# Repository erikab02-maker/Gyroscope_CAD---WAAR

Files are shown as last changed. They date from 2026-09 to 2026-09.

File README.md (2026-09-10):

I designed a gyroscope with Skye Kaser for the Washington Aerial Robotics Club (WAAR) at the University of Washington during the 2025-2026 academic year. Designing the gyroscope involved multiple design iterations, where I learned from each design to improve the following iteration in such a way as to reduce materials, improve safety factors and stability, and meet design requirements. This entire process allowed me to go through the design cycle from brainstorming ideas, to parameterizing the object in SolidWorks, 3D printing components, assembling components in real life, testing the gyroscope and re-designing. I went through two iterations of the design, with the first iteration having some problems with tolerances, the functionality of the rotation of the base, and the use of excess materials. After finding the areas of improvement I collaborated with Skye on how we could re-design or alter pre-existing CAD to engineer a second iteration of the gyroscope. The final product had significant improvement with the connection to the ball bearings in the top octagon by re-designing the connector, the base rotated much more easily, the base stand was designed to have more support and prevent bending while being transported and overall, less material was used which prevented warping when printing the components. Through the process of working with another engineer to design the gyroscope, I learned collaboration and teamwork skills by communicating design ideas and concerns for the functionality of certain components. I also gained experience utilizing SolidWorks to create the individual components, and in engineering design by going through the entire cycle of designing, evaluating and re-designing.

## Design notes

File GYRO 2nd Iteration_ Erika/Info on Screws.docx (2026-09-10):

Information on Screws

- 0.15 – 0.2 mm tolerance
- 2.5 mm diameter screws
- 8 mm length
- Have at least 6 mm depth to go into

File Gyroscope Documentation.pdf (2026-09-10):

# Gyroscope Test Bed

## Base Information

Test Name: Gyroscope Test Bed

Subsystem: Hardware

Authors: Erika Berreth and Skye Kaser

Date Executed: April 10th, 2026 - | July 6th, 2026
For Discovery Days: April 28th, 2026 - | May 1st, 2026

Location: University of Washington

Status: Completed

## Objective

The objective of this design is to create a gyroscope that has the degrees of freedom to rotate about the x, y, and x axis so that roll, pitch, and yaw capabilities are simulated about the drone. The gyroscope’s purpose is to allow the software team to fine tune the PID controller by simulating disturbances in all degrees of freedom with the gyroscope.

## Related Documents

Link to Bearing Orders: Current Order | McMaster-Carr (https://www.mcmaster.com/orders/)

Design Model Website: 3D Flight Lab – 3DFlightlab (https://3dflightlab.com/)

Gyroscope CAD Folder: WAAR_Gyro_Iteration01and02_2026_ErikaAndSkye (https://drive.google.com/drive/folders/1tEqzYJV6UX54x_FTIXxHvfCaPLfKlcOg?usp=drive_link)

## Equipment

Ball Bearing, 0.25’’ diameter (x 4)

Needle-Roller Thrust Bearing with 2.5’’ diameter (x 1)

0.032" Thick Washer for 2.5" Shaft Diameter Needle-Roller Thrust Bearing (x 2 )

Gyroscope Test Bed | 1

PLA for 3D printing

PVC pipe with 0.5 inch diameter

Add screws

## Requirements and Constraints

Requirement | Value | Notes | Status
Degrees of Freedom | = 3 DOF | Must have pitch, roll and yaw capabilities. | MET
Safety Requirements | The design must create a cage around the drone, and the drone must be rigidly mounted. | Prevent user injury and damage during operation. | MET
Load Capabilities | The gyroscope should be able to withstand vibrations from the drone and rotational forces. | Ensures structural integrity under forces and vibrations from the drone. | MET
Cost | The gyroscope should be less than $60. | Try to keep bearings under $5 each. | MET

## Design Idea

The gyroscope will look similar to the design as seen below in Figure 1, with an octagonal top structure that has two degrees of freedom and four ball bearings, and a base that has one degree of freedom and two thrust bearings. The drone will be attached to the drone support frame with ideally four velcro straps or zip ties.

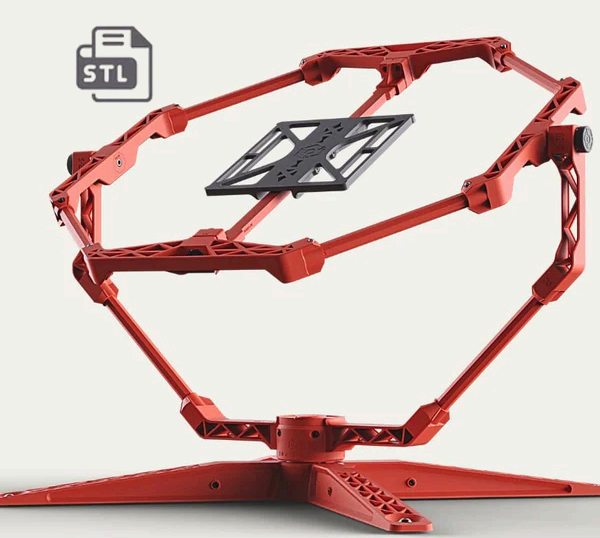
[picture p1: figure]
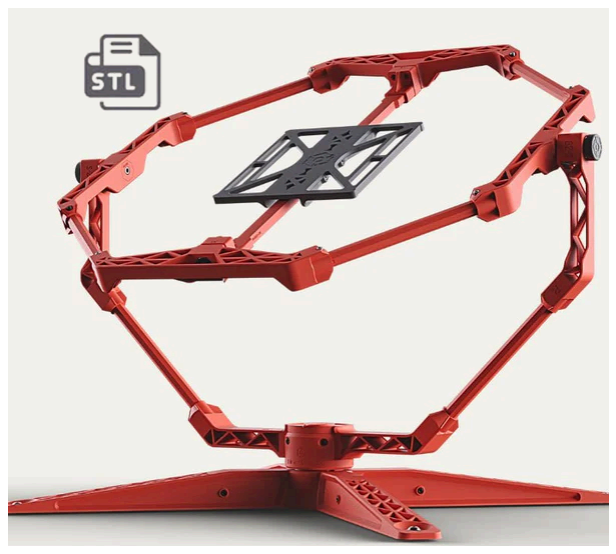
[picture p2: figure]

## Design Procedure

Overview

Figure 1: Image of the inspiration behind the model for the gyroscope.

Following the design of the previously shown image to create a fully 3D printed gyroscope utilizing the cheapest and quickest methods. Time is of the essence and cost is a factor. Bearings were selected to fit a tight cost criteria and the design will revolve around them. If the budget allows, larger thrust bearings can be purchased to better support the weight of the drone and prevent wobbling. The base stand, base, base connectors, vertical connectors, and four components of the octagon were designed in SolidWorks. The thin circular rods that connect each of the components was not 3D printed but made of PVC. No bearing caps were needed like in the image, as the ball bearings were designed to fit in a small cut extrude feature. The base stand was made to be a shelled component, that was filled with sand for weight.

Vertical Connector to Octagon

The gyroscope was designed to connect the vertical connector with one side of the octagon, and allow rotation at that point with a ball bearing. The side of the octagon had a hole in it with which the bearing fit into, and the vertical connector had an adapter on it’s side which fit into the inner diameter of the bearing. See images below for clarification, where Figure 2 shows how the bearing fit into one side of the octagon, Figure 3 shows a close up of the rotational joint, and Figure 4 shows the entire assembly.

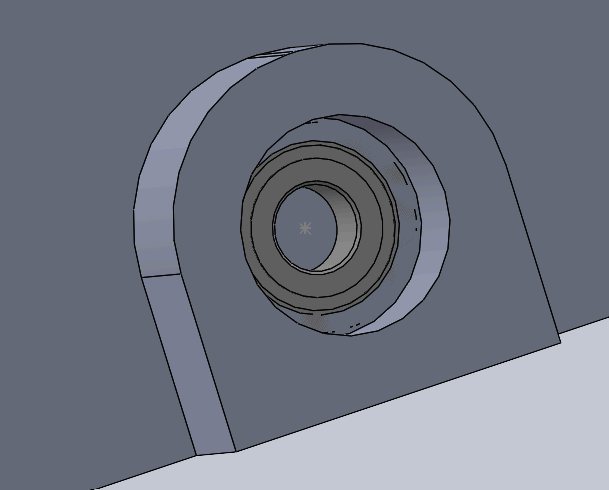
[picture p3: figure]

Figure 2: | Bearing in extrude cut feature.

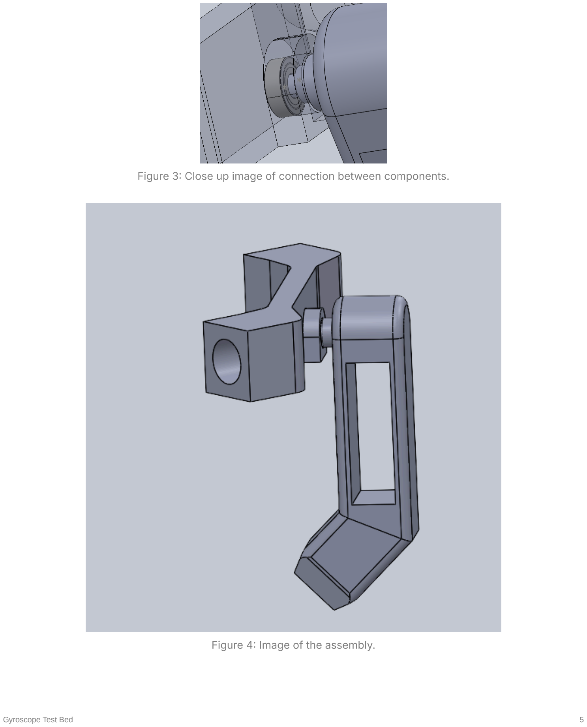
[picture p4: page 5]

Figure 3: | Close up image of connection between components.
Figure 4: | Image of the assembly.

Base Design

The base was designed so that with weight-bearing from the loaded payload, the base would compress slightly. That is why there are slight gaps between the components. The vertical connector slots in from the side and a pin is pushed in from the top to secure it in place. Two thrust bearings of different sizes are used to allow for proper rotation of the base, while minimizing friction. A nut is screwed from the top through the center of the base to secure all the vertically stacked components together. When assembled and tested there was a slight wobble to the base when rotating about the z-axis, due to less compression of the components than initially predicted when loaded. However, adding a second thrust bearing and making other modifications reduced the friction enough that three degrees of freedom were achieved for testing purposes.

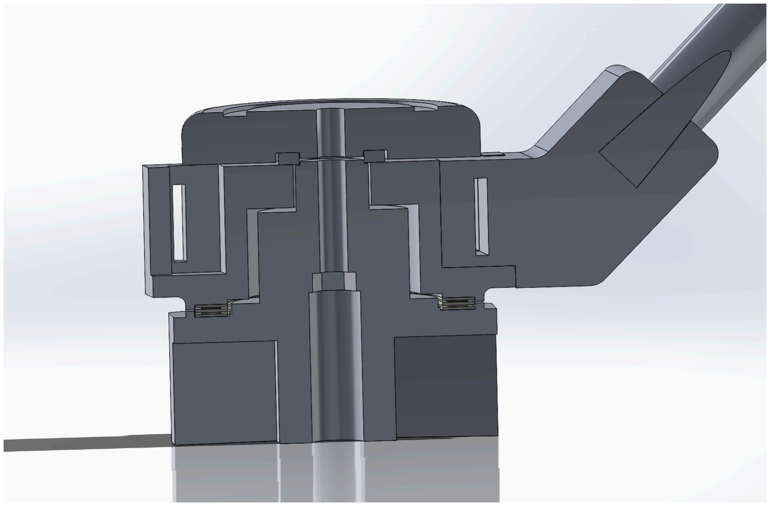
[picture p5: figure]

## Issues & Iteration Improvement

Figure 5: | …

First Iteration Issues

Cracking noticed around dovetail connections on base

Base connectors slightly too high

Excessive friction on thrust bearing connection

Existing PVC connections required glue to be stable, tolerance is too great

Ball bearing connection needed an adapter to function

Some warping of components from 3D printing

Second Iteration Issues and Fixes

Some wobbling in the base when there is rotation in multiple degrees of freedom

Some tolerance issues in the PVC connections, which were fixed by printing adapters

Drone support frame was outdated and had to be re-designed

PVC attaching from the base to the vertical connectors was too long, and trimmed by 0.3 inches on each side

Screws tended to pull up material from the components, and so were often screwed in partially

The gyroscope was balanced properly by screwing on some washers to the octagon

Second Iteration Improvements

Base (with thrust bearing) rotated much more smoothly than before, and reduced previous wobbling a little

The base was completely re-designed and went from having one to two bearings

Base supports were successfully re-designed to prevent cracking

Ball bearing connection/socket was re-designed to have a tight fit and allow easy rotation

Material was reduced on components in the octagon while maintaining stability

Strengthened weakened areas with more material or by re-designing the area

Redesign PVC mounting to use screws or some other method that eliminates the need for glue

## Conclusions

The first iteration of the gyroscope had substantial issues that prevented functionality in all three degrees of freedom. The base had a lot of friction while rotating, and the ball bearings did not connect well with the proper components. PVC connections required glue to be stable and there were a few issues with tolerancing. In the second iteration there were also problems that came up, but those issues had easy fixes and generally didn’t influence the functionality of the gyroscope. Balancing the gyroscope involved screwing on a few washers on one side of the octagon, and there were issues with accurately cutting the PVC to the intended size as a hand saw was used. Due to small discrepancies in the length, some of the PVC had to be trimmed down. However, in general the base rotated much better than before, and by using screws instead of glue the entire gyroscope was much more stable. The finished product was able to be used to fine tune the PID controller, and will ideally last for another year.

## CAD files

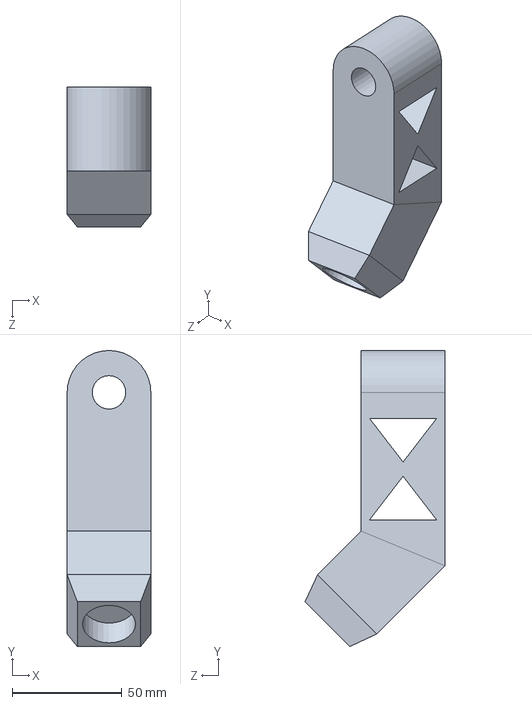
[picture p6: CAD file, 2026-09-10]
Gyro 1st Iteration_Erika/Gryo_second_side_connector_05.SLDPRT
38.1 x 134.6 x 63.6 mm

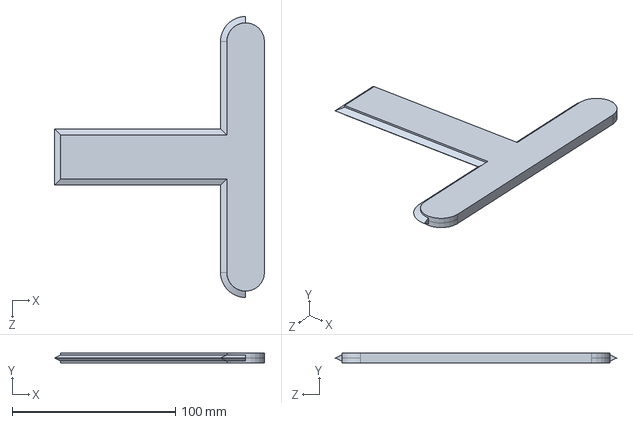
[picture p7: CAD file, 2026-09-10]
GYRO 2nd Iteration_ Erika/base_lid_05.SLDPRT
128.6 x 6.00 x 172.0 mm

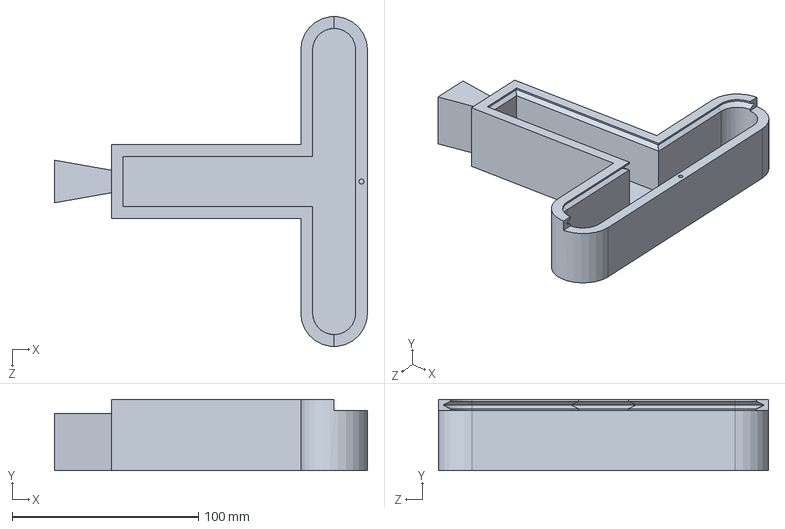
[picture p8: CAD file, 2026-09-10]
GYRO 2nd Iteration_ Erika/Final/base_05_Erika.SLDPRT
167.9 x 38.1 x 177.0 mm

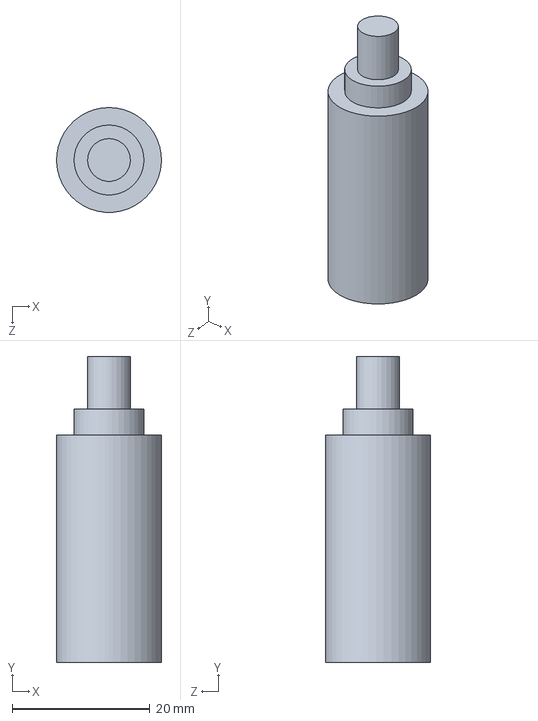
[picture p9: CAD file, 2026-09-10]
GYRO 2nd Iteration_ Erika/Final/Not in use/adapter_erika_01.SLDPRT
15.2 x 44.5 x 15.2 mm

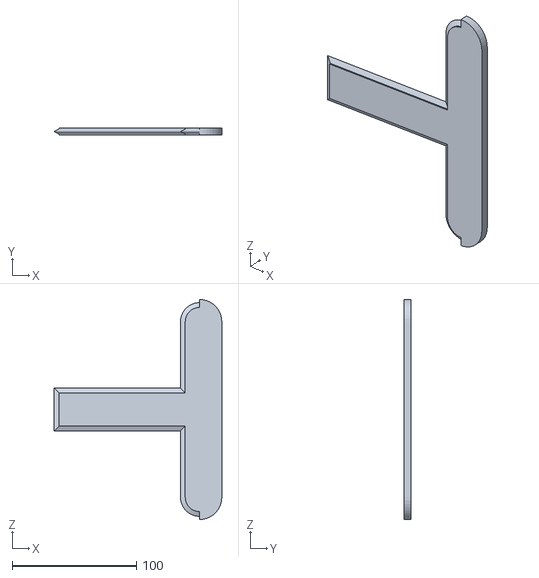
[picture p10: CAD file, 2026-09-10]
GYRO 2nd Iteration_ Erika/Final/STL/base_lid_07.STL
134.9 x 6.00 x 177.0

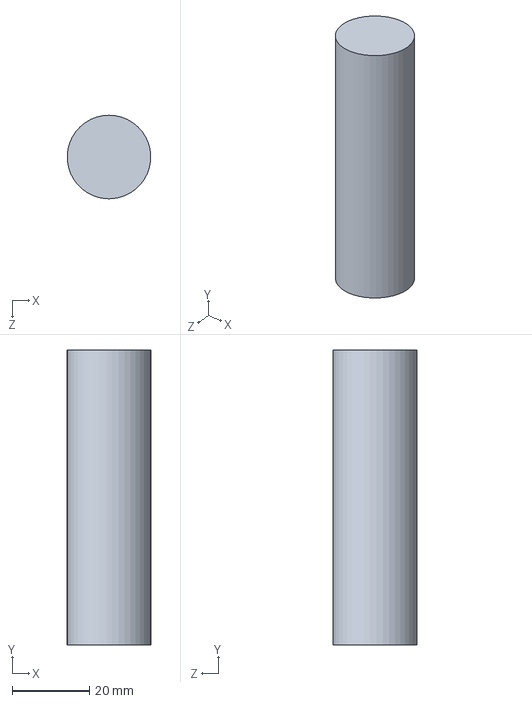
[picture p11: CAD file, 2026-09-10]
Gyro FINAL CAD/Gyro_Support_PVC_Skye_V2.0.SLDPRT
21.6 x 76.2 x 21.6 mm

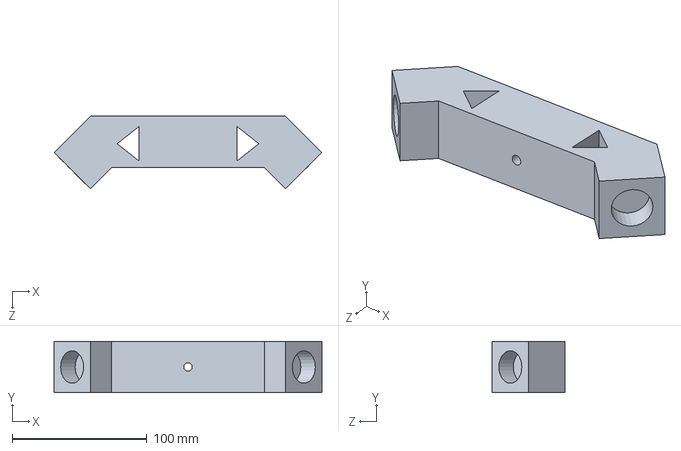
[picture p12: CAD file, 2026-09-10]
Gyro 1st Iteration_Erika/Gryo_side_connector_03.SLDPRT
199.0 x 38.1 x 53.9 mm

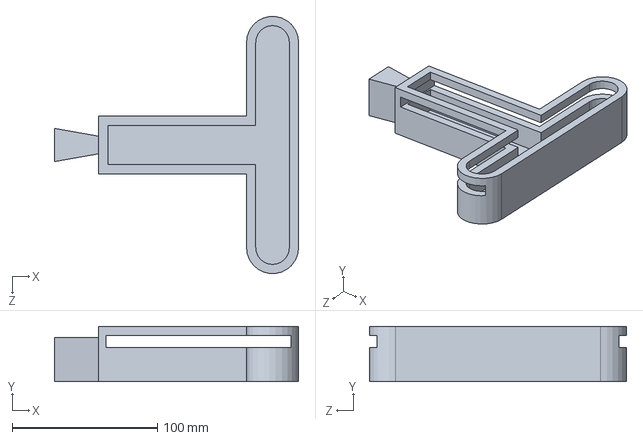
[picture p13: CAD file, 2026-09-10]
GYRO 2nd Iteration_ Erika/base_03.SLDPRT
167.9 x 38.1 x 176.7 mm

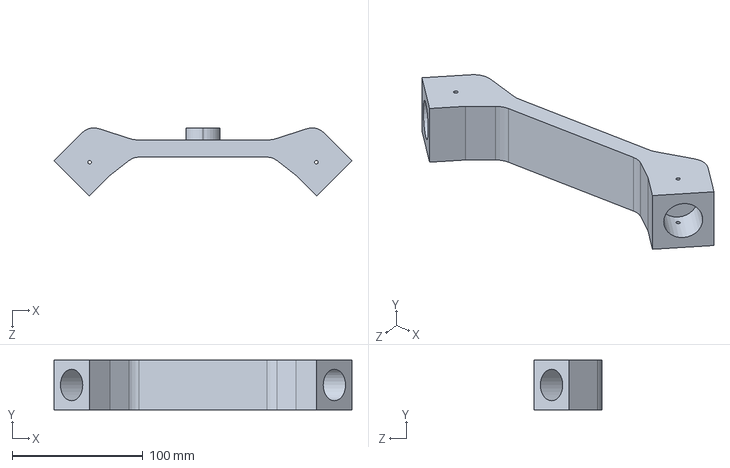
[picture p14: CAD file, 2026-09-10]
GYRO 2nd Iteration_ Erika/Final/Gryo_horizontal_connector_06_Erika.SLDPRT
227.7 x 38.1 x 52.1 mm

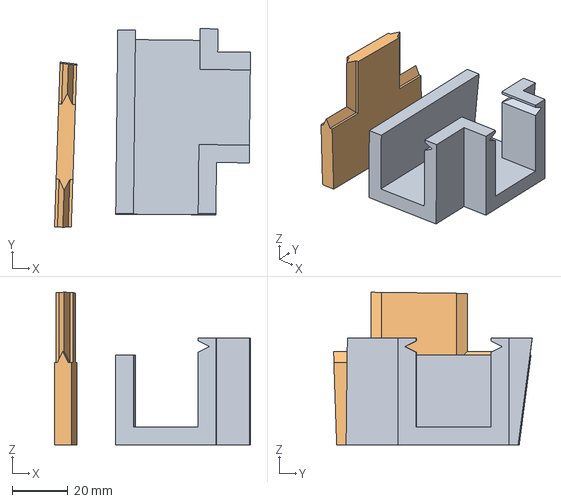
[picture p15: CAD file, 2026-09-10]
GYRO 2nd Iteration_ Erika/Final/STL/base_slice.3mf
70.0 x 71.0 x 54.5 mm
base_04.STL
base_lid_07.STL

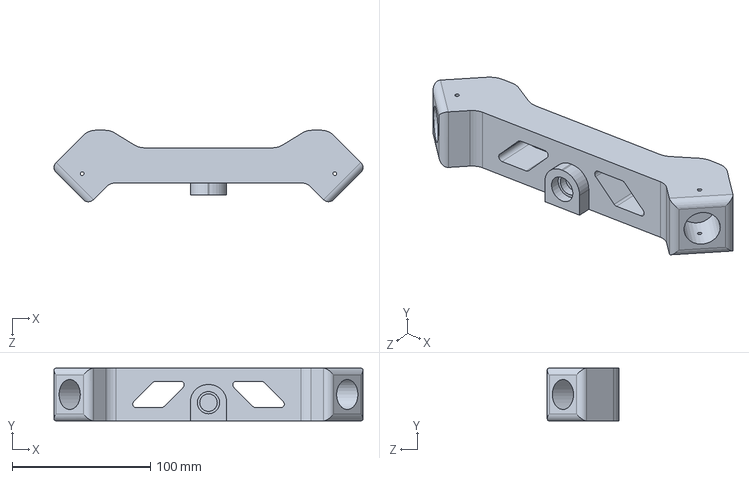
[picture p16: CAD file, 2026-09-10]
Gyro FINAL CAD/Gyro_support_frame_connector_Skye_V2.0.SLDPRT
223.5 x 38.1 x 51.8 mm

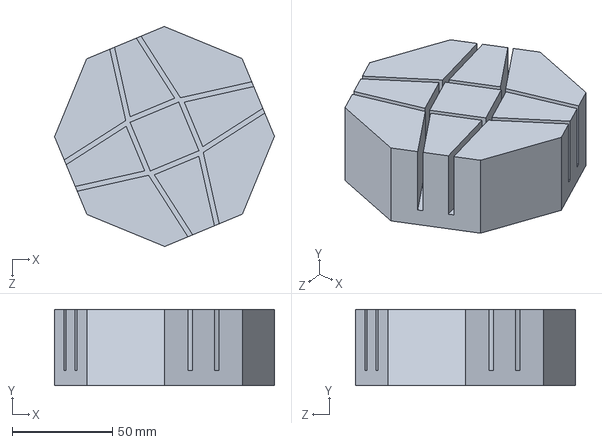
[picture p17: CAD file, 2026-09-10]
Gyro 1st Iteration_Erika/Gryro_octagon_01.SLDPRT
109.9 x 38.1 x 109.9 mm

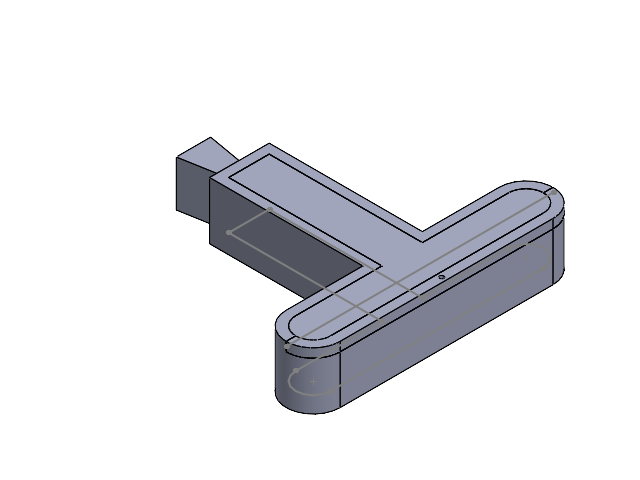
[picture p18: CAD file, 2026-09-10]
GYRO 2nd Iteration_ Erika/Final/Assembly - base.SLDASM
base_05_Erika
base_lid_08_Erika

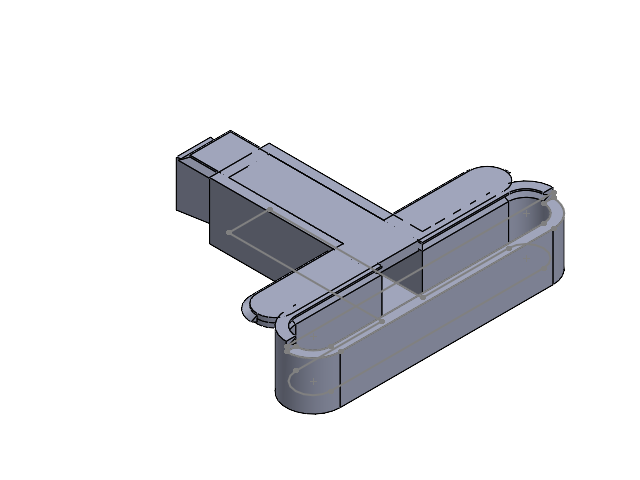
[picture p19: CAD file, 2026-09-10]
GYRO 2nd Iteration_ Erika/Assemble1.SLDASM
base_legs_(slide_in_lid)_04
base_legs_(slide_in_lid)_06

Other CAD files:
Gyro FINAL CAD/Gyro_Assembly_Skye_V2.0.SLDASM
GYRO 2nd Iteration_ Erika/Final/Assembly - connectors.SLDASM
Gyro 1st Iteration_Erika/Gyro_base_mate_01.SLDASM
GYRO 2nd Iteration_ Erika/Final/Gryo_horizontal_connector_05.SLDPRT
GYRO 2nd Iteration_ Erika/Final/Gryo_vertical_connector_09_Erika.SLDPRT
GYRO 2nd Iteration_ Erika/Final/Gryo_vertical_connector_10_Erika.SLDPRT
GYRO 2nd Iteration_ Erika/Final/Gyro_support_frame_connector_Skye_02.SLDPRT
GYRO 2nd Iteration_ Erika/Final/STL/base_04.STL
GYRO 2nd Iteration_ Erika/Final/base_04_Erika.SLDPRT
GYRO 2nd Iteration_ Erika/Final/base_lid_07_Erika.SLDPRT
GYRO 2nd Iteration_ Erika/Final/base_lid_08_Erika.SLDPRT
GYRO 2nd Iteration_ Erika/Gryo_side_connector_04.SLDPRT
GYRO 2nd Iteration_ Erika/Gryo_vertical_connector_08.SLDPRT
GYRO 2nd Iteration_ Erika/base_01.SLDPRT
GYRO 2nd Iteration_ Erika/base_02.SLDPRT
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
